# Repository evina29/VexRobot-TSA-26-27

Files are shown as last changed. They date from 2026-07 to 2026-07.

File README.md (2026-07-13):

# Collector Bot

A VEX V5 robot that drives around, lifts its arm, and picks stuff up with a
claw. I built it from VEX metal parts, four motors, and a V5 brain, and wrote
the code in C++ with [PROS](https://pros.cs.purdue.edu/).

## About this project

Collector Bot is my individual project. I've been working on it since April
2026, I made it for Stardance Hack Club, and I'm planning to use it in the
2026 to 2027 TSA (Technology Student Association) year.

I made it because I wanted a robot that could actually collect and carry
things, not just drive around. Also, building one thing where the mechanics,
the electronics, and the code all have to work together teaches you way more
than doing any of those on their own.

## What it does

You drive it with the V5 controller. You lower the arm over an object, close
the claw to grab it, lift it up, and carry it wherever you want. It also has a
small autonomous routine where it drives forward on its own for one second,
which is for the autonomous part of a match.

## The robot

* **Drivetrain:** two drive motors (one per side) with tank style controls
* **Arm:** a motor powered lift made of two long metal beams with gears
* **Claw:** a motor that opens and closes to grab and let go of objects
* **Brain:** VEX V5 brain running the PROS kernel

The arm and claw motors use HOLD brake mode, so when you let go of the buttons
the arm stays up and the claw keeps its grip instead of dropping everything.

## Controls

| Control | What it does |
|---|---|
| Left joystick (up/down) | Left wheels forward/backward |
| Right joystick (up/down) | Right wheels forward/backward |
| R1 | Lift the arm up |
| R2 | Lower the arm down |
| L1 | Close the claw (grab) |
| L2 | Open the claw (let go) |

## Motor ports

| Port | Motor |
|---|---|
| 1 | Left drive |
| 2 | Right drive (reversed) |
| 3 | Arm |
| 4 | Claw |

## Wiring

Everything connects with VEX V5 smart cables from the brain to the motors.
There's no PCB or custom wiring in this project.

Wiring diagram

## How to run it from a laptop

1. Install [VS Code](https://code.visualstudio.com/) and the
   [PROS extension](https://marketplace.visualstudio.com/items?itemName=sigbots.pros)
   from the VS Code marketplace.
2. Download this repository (green **Code** button, then **Download ZIP**, then
   unzip it) and open the folder in VS Code.
3. Click the PROS icon in the left sidebar and hit **Build**. It should finish
   with no errors.
4. Plug the V5 brain into the laptop with a USB cable and turn the brain on.
5. Hit **Upload** in the PROS sidebar to send the program to the brain.
6. On the brain's touchscreen, open **Programs** and run the program.
7. Turn on the V5 controller (it has to be paired with the brain) and drive.

## Code

All the robot code is in [`src/main.cpp`](src/main.cpp):

* `initialize()` runs once at startup and sets up the screen and brake modes
* `autonomous()` drives forward for one second on its own
* `opcontrol()` is the main driving loop that reads the controller 50 times a
  second and moves the wheels, arm, and claw

## Devlog

The whole build journal, from the first parts to the finished code, is in
[JOURNAL.md](JOURNAL.md).

## Pictures of Bot



## 3D model

3D model render

There's a simplified 3D model of the robot in
[cad/collector_bot.stl](cad/collector_bot.stl), which GitHub can open in a 3D
viewer. Quick note on this: I designed and built the robot physically, not in
CAD, so this model is a recreation I made after the build. It's generated by a
Python script, [cad/generate_model.py](cad/generate_model.py), that builds the
drive base, omni wheels, brain, towers, geared arm, and claw out of simple
shapes using the robot's real approximate measurements. The image above is
rendered straight from the STL by
[cad/render_model.py](cad/render_model.py).

The same model is also saved as a STEP file,
[cad/collector_bot.step](cad/collector_bot.step), made by
[cad/generate_step.py](cad/generate_step.py) with cadquery. The STEP one has
each part colored like the real robot (silver metal, red and green gears,
black motors) and opens in any CAD program like Onshape, Fusion, or FreeCAD.

## Bill of materials

This same list with the same links is also in [bom.csv](bom.csv) in the root
of the repository.

| Part | Quantity | Link |
|---|---|---|
| VEX V5 Brain | 1 | [vexrobotics.com](https://www.vexrobotics.com/276-4810.html) |
| VEX V5 Controller | 1 | [vexrobotics.com](https://www.vexrobotics.com/276-4820.html) |
| VEX V5 Battery | 1 | [vexrobotics.com](https://www.vexrobotics.com/276-4811.html) |
| V5 Smart Motors | 4 (2 drive, 1 arm, 1 claw) | [vexrobotics.com](https://www.vexrobotics.com/276-4840.html) |
| Omni wheels | 4 | [vexrobotics.com](https://www.vexrobotics.com/omni-wheels.html) |
| High strength gears (red and green) | assorted | [vexrobotics.com](https://www.vexrobotics.com/gears.html) |
| Metal C channels, plates, axles, and standoffs | assorted | [vexrobotics.com](https://www.vexrobotics.com/structure.html) |
| Screws, nuts, spacers, and shaft collars | assorted | [vexrobotics.com](https://www.vexrobotics.com/hardware.html) |
| V5 Smart Cables | 4 | [vexrobotics.com](https://www.vexrobotics.com/catalogsearch/result/?q=v5+smart+cable) |

## License

This project is open source under the MIT License. See [LICENSE](LICENSE).

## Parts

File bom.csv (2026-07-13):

Part | Quantity | Notes | Link
VEX V5 Brain | 1 | robot controller with touchscreen | https://www.vexrobotics.com/276-4810.html
VEX V5 Controller | 1 | wireless driver controller | https://www.vexrobotics.com/276-4820.html
VEX V5 Battery | 1 | powers the brain and motors | https://www.vexrobotics.com/276-4811.html
VEX V5 Smart Motor | 4 | 2 drive and 1 arm and 1 claw | https://www.vexrobotics.com/276-4840.html
Omni wheels | 4 | drive wheels | https://www.vexrobotics.com/omni-wheels.html
High strength gears | assorted | red and green gears for the arm and drive | https://www.vexrobotics.com/gears.html
Metal C channels and plates | assorted | chassis and towers and arm beams | https://www.vexrobotics.com/structure.html
Axles and standoffs and screws and nuts and collars | assorted | structural hardware | https://www.vexrobotics.com/hardware.html
V5 Smart Cables | 4 | connect motors to the brain | https://www.vexrobotics.com/catalogsearch/result/?q=v5+smart+cable

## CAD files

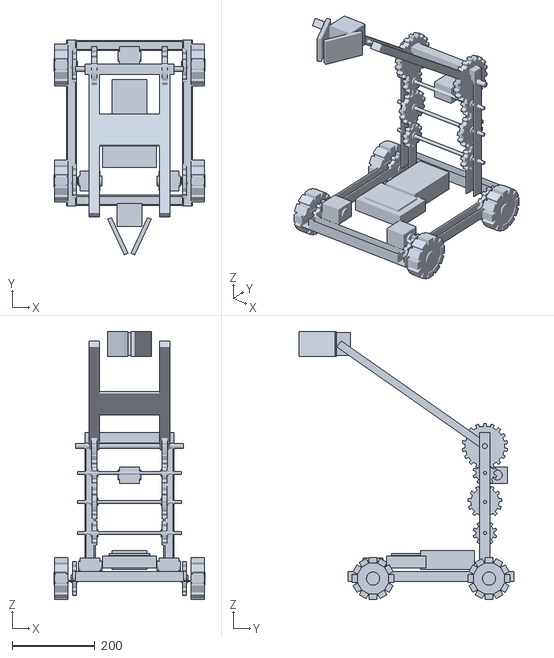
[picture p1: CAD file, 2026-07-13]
cad/collector_bot.stl
364.0 x 518.7 x 647.1

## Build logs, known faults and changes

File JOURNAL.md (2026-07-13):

# Collector Bot Engineering Journal

**Student:** Evina Shingavi
**Project:** Collector Bot (VEX V5)
**Time period:** April 2026 to July 12, 2026
**Average time spent:** about 5 hours a week, so roughly 70 hours total

Quick note about how this journal is written: I didn't keep a written log
while I was building the robot. I reconstructed the weekly entries below from
memory on July 12, 2026, using my photos and the order I remember doing things
in, so the week labels are approximate. The last week and everything after it
was written as it happened, and you can check it against the commit history of
this repository.

---

## Week 1: April 1 to 5, 2026

This was the start of the project. I spent most of the week figuring out what
kind of robot I even wanted to build. I looked at a bunch of VEX robot
designs, and the one that stuck with me was the official VEX V5 Clawbot. I
used it as my inspiration: I liked the idea of a robot that drives, lifts,
and grabs, but I wanted to design my own version instead of following the kit
instructions. Mine ended up pretty different, with taller towers, a longer
two beam arm driven by a gear train, and omni wheels on a bigger chassis.
I sketched out a few ideas and settled on that direction.

One of the robots I looked at in person while I was deciding what to build:

a robot I looked at for inspiration

I also dumped out all my VEX parts and sorted the hardware into groups so I
knew what I actually had and what I might need to get later.

### Challenges

* I wasn't sure which arm design would be strong enough to actually lift
  things.
* A couple of my sketches were way too big and would have needed more parts
  than I had.

### What I did about it

* Simplified the design.
* Went with a compact drivetrain plus one lifting arm and a claw.
* Did some rough measurements before starting to build.

## Week 2: April 6 to 12, 2026

I started building the drivetrain with VEX C channels, wheels, shafts,
bearings, and two V5 motors. I wanted a solid base before adding anything
else.

I got the frame together and mounted the wheels. When I pushed the robot
across the floor by hand, one side rolled worse than the other.

### Challenges

* The wheel alignment was a little off.
* Some bearings weren't seated right.

### What I did about it

* Took apart and rebuilt part of the chassis.
* Fixed the bearing positions.
* Tightened everything and checked the spacing between parts.

By the end of the week the drivetrain frame was done.

The first version of the drive base:

first version of the drive base

## Week 3: April 13 to 19, 2026

This week was the first arm prototype. I built a simple lifting mechanism out
of metal beams, gears, and shafts.

It technically worked, but it had problems right away. It was heavier than I
expected and it was really straining the motor.

The first arm prototype, with the big gears mounted on the beams:

first arm prototype with gears

### Challenges

* The arm was too heavy to lift well.
* The gears slipped sometimes while it moved.

### What I did about it

* Tried a few different gear setups.
* Wrote down what I noticed about the lifting.
* Started planning a redesign to cut weight and get better leverage.

## Week 4: April 20 to 26, 2026

I finished the first arm redesign. The whole point was making it lighter
without losing lifting strength.

I took off several metal pieces and went with a simpler structure, and moved
the gears around to get better torque.

### Challenges

* The arm got lighter but started wobbling side to side.
* Taking off support pieces made the whole thing less rigid.

### What I did about it

* Added some temporary braces.
* Tried different mounting spots.
* Started planning a second redesign, this time for stability.

## Week 5: April 27 to May 3, 2026

This week was about making the arm sturdier. I added more support beams to cut
down the wobble.

Testing went a lot better than the earlier versions.

### Challenges

* The arm alignment kept shifting after moving it a bunch of times.
* Some screws came loose during testing.

### What I did about it

* Retightened all the hardware.
* Added extra supports near the pivot.
* Started doing a quick check of the hardware before every testing session.

## Week 6: May 4 to 10, 2026

I started building the first claw.

The first version was pretty small and only really meant for light objects.

### Challenges

* The claw didn't open wide enough.
* Things kept slipping out while lifting.

### What I did about it

* Changed the claw dimensions.
* Moved the pivot points.
* Tested the grip on different sized objects.

It worked, but I knew it needed a redesign.

## Week 7: May 11 to 17, 2026

I rebuilt the claw with longer metal pieces so it opens wider and handles
objects better.

I also added rubber bands to help it grip and hold on to stuff.

### Challenges

* The grip strength was still inconsistent.
* Some objects would rotate while getting lifted.

### What I did about it

* Messed around with the rubber band placement until it worked.
* Adjusted the claw geometry.
* Kept testing with different kinds of objects.

The rebuilt claw on the end of the arm:

the rebuilt claw

Way better than the first claw.

## Week 8: May 18 to 24, 2026

This week I put the arm and claw together into one system. First time all the
main mechanisms of the robot were actually connected.

The gear train that drives the arm, coming together on the towers:

arm gear train on the towers

### Challenges

* The combined weight made the arm perform worse.
* The center of gravity moved around when lifting.

### What I did about it

* Strengthened where the arm mounts.
* Moved things around on the chassis to rebalance it.
* Did a bunch of lift tests over and over.

## Week 9: May 25 to 31, 2026

Some parts I ordered hadn't shown up yet, so I couldn't do the final assembly
work I wanted to do.

Instead of just stopping, I used the week to plan improvements, go over my
designs, and update my notes.

### Challenges

* Missing parts meant I couldn't do the reinforcement work.
* Not much testing was possible.

### What I did about it

* Went back through my design notes.
* Made a list of the weak points that needed reinforcement.
* Planned out the next changes.

## Week 10: June 1 to 7, 2026

The parts finally came, so work started back up.

I reinforced the arm with more support beams and swapped out some of the
temporary pieces.

### Challenges

* The existing mounting holes didn't line up with the new supports.
* I had to partially take the robot apart to install them.

### What I did about it

* Changed the mounting locations.
* Put the sections back together.
* Tested it to make sure the structure actually improved.

The arm felt way more stable after this.

Mid rebuild on my work table:

mid rebuild on the work table

## Week 11: June 8 to 14, 2026

Lots of mechanical testing this week.

While running it over and over, I noticed one of the arm supports shifting a
little under load.

### Challenges

* An arm support moved during testing.
* Lifting over and over caused small alignment changes.

### What I did about it

* Repositioned the support beams.
* Tightened all the hardware again.
* Started inspecting things before each test.

It got a lot more reliable after that.

An earlier full version of the robot that I put together and tested. Parts of
this version changed later, like the claw and the wheels, but it let me test
everything working together:

an earlier full test version of the robot
top view of the earlier test version

## Week 12: June 15 to 21, 2026

This week was final mechanical cleanup. I went through every subsystem,
checked that the hardware was tight, and looked for anything rubbing or
interfering.

### Challenges

* There were still some small alignment issues.
* Certain fasteners kept loosening over time.

### What I did about it

* Replaced the worn hardware.
* Rechecked all the moving parts.
* Ran longer testing sessions.

## Week 13: June 22 to 28, 2026

Finished up the assembly work and got the robot ready for programming.

At this point it could drive, lift, and grip reliably, at least mechanically.

Almost fully assembled:

robot almost fully assembled

### Challenges

* There was still a little frame flex under heavier loads.

### What I did about it

* Added more reinforcement.
* Did one last round of mechanical checks.

## Week 14: June 29 to July 5, 2026

This week was mostly review and getting ready to write the code.

I went through the motor ports, the wiring paths, and the overall organization
of the robot.

### Challenges

* Some wires were running too close to moving parts.

### What I did about it

* Cleaned up the cable management.
* Secured the wires with zip ties and rerouted the bad ones.

## Week 15: July 6 to 12, 2026

The last week was all software and documentation. Unlike the earlier weeks,
everything from here on was written down as it happened, and you can check all
of it against the commit history.

### July 12: The complete program, and a real repository

* Wrote the whole driver control program in C++ with PROS. Tank drive on the
  joysticks, R1/R2 for the arm, L1/L2 for the claw, plus a one second
  autonomous routine that drives forward.
* Learned about motor brake modes. The arm and claw use HOLD mode, so the arm
  stays up and the claw keeps its grip when I let go of the buttons.
* One drive motor spun the wrong way during controller testing, so I reversed
  the right drive motor in the code.
* Added a joystick deadband so the robot doesn't slowly creep when the sticks
  aren't perfectly centered.
* Ran into a real build problem: the newest PROS kernel (4.2.2) wants the
  gnu++26 compiler standard, but the toolchain that comes with the PROS VS
  Code extension only goes up to gnu++20. Fixed it by changing the C and C++
  standards in common.mk, and after that it compiled clean.
* Set the project up as a proper repository: everything at the root, a README
  that explains the robot and how to run it, an MIT license, and this journal.
* Also learned the hard way that uploading files to GitHub through the browser
  skips folders. My first upload was missing src, include, and firmware, so
  the repo literally had no code in it. Fixed it by pushing with git instead.

### July 12: First test on the real robot

Uploaded the program to the V5 brain and ran it on the actual robot for the
first time. It works. The robot drives and moves with the controller, so the
code and the hardware finally met and did their job together.

The finished robot can:

* Drive with tank controls.
* Lift and lower objects with the arm.
* Grab and release objects with the claw.
* Hold the arm position with brake mode.
* Run a basic autonomous routine.

### July 12, later that evening: 3D model files

A reviewer looking at my submission asked about 3D model files. I never
designed this robot in CAD. I built it straight from VEX parts and iterated on
the physical robot, so there were no model files to add. To fill that gap I
made a simplified 3D model of the finished robot as an STL file, generated by
a Python script (cad/generate_model.py) that builds the drive base, omni
wheels, brain, towers, geared arm, and claw out of boxes and cylinders using
the robot's real approximate measurements. Just to be clear about the order of
events: the robot came first, and this model is a recreation of it, not the
design it was built from.

Later I extended it into a proper CAD format too: a STEP file with 272 colored
parts (silver metal, red and green gears, black motors), generated with
cadquery by cad/generate_step.py. I also added a rendered image of the model
to the README, a wiring diagram, and a bill of materials with links, both as a
table in the README and as bom.csv in the root of the repository.

### Next steps

* Tune the arm and claw speeds now that the program runs on the robot.
* Improve the autonomous routine.
* Add sensors for more accurate movement.
* Make the claw grip stronger.
* Practice driving for TSA competitions during the 2026 to 2027 season.

### Reflection

This project taught me a lot about iteration, testing, and just sticking with
it. The arm and claw both needed multiple redesigns before they worked
reliably, and fixing one mechanical problem usually revealed another one I
hadn't noticed during planning. By writing down what went wrong and improving
the design piece by piece, I ended up with a working VEX V5 robot that does
what I originally wanted it to do.

### Pictures of Robot





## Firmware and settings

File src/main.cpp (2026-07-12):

#include "main.h"

// Collector Bot: a VEX V5 robot that drives around, lifts its arm,
// and grabs objects with its claw.

pros::Controller master(pros::E_CONTROLLER_MASTER);

pros::Motor left_drive(1);    // left wheel motor
pros::Motor right_drive(-2);  // right wheel motor, reversed so both wheels push forward
pros::Motor arm(3);           // lifts the arm up and down
pros::Motor claw(4);          // opens and closes the claw

const int ARM_SPEED = 90;   // arm speed out of 127
const int CLAW_SPEED = 90;  // claw speed out of 127

// Runs once when the program starts.
void initialize() {
	pros::lcd::initialize();
	pros::lcd::set_text(1, "Collector Bot is ready!");

	// HOLD keeps the motor locked in place when it stops,
	// so the arm stays up and the claw keeps its grip.
	arm.set_brake_mode(pros::E_MOTOR_BRAKE_HOLD);
	claw.set_brake_mode(pros::E_MOTOR_BRAKE_HOLD);
}

void disabled() {}

void competition_initialize() {}

// Runs by itself during the autonomous part of a match:
// drives forward for one second, then stops.
void autonomous() {
	left_drive.move(80);
	right_drive.move(80);
	pros::delay(1000);
	left_drive.move(0);
	right_drive.move(0);
}

// Runs while a person drives the robot with the controller.
void opcontrol() {
	while (true) {
		// Tank drive: left stick controls the left wheel,
		// right stick controls the right wheel.
		int left_speed = master.get_analog(pros::E_CONTROLLER_ANALOG_LEFT_Y);
		int right_speed = master.get_analog(pros::E_CONTROLLER_ANALOG_RIGHT_Y);

		// Ignore tiny stick movements so the robot doesn't creep.
		if (left_speed > -8 && left_speed < 8) left_speed = 0;
		if (right_speed > -8 && right_speed < 8) right_speed = 0;

		left_drive.move(left_speed);
		right_drive.move(right_speed);

		// Arm: R1 lifts up, R2 lowers down, otherwise hold in place.
		if (master.get_digital(pros::E_CONTROLLER_DIGITAL_R1)) {
			arm.move(ARM_SPEED);
		} else if (master.get_digital(pros::E_CONTROLLER_DIGITAL_R2)) {
			arm.move(-ARM_SPEED);
		} else {
			arm.brake();
		}

		// Claw: L1 grabs, L2 lets go, otherwise keep the grip.
		if (master.get_digital(pros::E_CONTROLLER_DIGITAL_L1)) {
			claw.move(CLAW_SPEED);
		} else if (master.get_digital(pros::E_CONTROLLER_DIGITAL_L2)) {
			claw.move(-CLAW_SPEED);
		} else {
			claw.brake();
		}

		pros::delay(20);  // update 50 times per second
	}
}

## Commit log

2026-07-12 Collector Bot: VEX V5 robot with drive, arm, and claw
2026-07-13 Add a simplified 3D model of the robot with its generator script
    [collector_bot.stl]
2026-07-13 Make the 3D model more detailed to match the real robot
    [collector_bot.stl]
2026-07-13 Add BOM with links, wiring diagram, and 3D model render
    [bom.csv]
2026-07-13 Insert additional images into JOURNAL.md
    Added multiple images to the journal.
